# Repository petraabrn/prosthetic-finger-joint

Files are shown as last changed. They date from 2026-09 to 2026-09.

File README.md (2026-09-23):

# Cable-Driven Prosthetic Finger Joint & Testing Rig

> **A motorized, cable-actuated prosthetic finger prototype featuring tactile force feedback, rapid 3D prototyping, and Arduino control.**

This project is an experimental prototype of an articulated prosthetic finger that curls and extends using motorized pull strings (cables). Built as a low-cost mechatronics prototype, the setup combines mechanical 3D-printed parts, a motor drive system, and sensors to detect touch and adjust grip.

---

## 1. How the System Works

```text
               [ Arduino Controller (C++) ]
                            │
        ┌───────────────────┴───────────────────┐
        ▼                                       ▼
 [ Motor & Cable Rig ]                   [ Sensor Feedback ]
 • Servo / Stepper Motor                 • Pressure sensor (force-sensitive)
 • Motor Pulley                          • Ultrasonic distance sensor
 • Nylon tendon cable (pulls finger)     • Visual LED indicator
        │                                       │
        └───────────────────┬───────────────────┘
                            ▼
                [ 3D-Printed Finger ]
                • 3-joint trapezoidal segments
                • Paracord spine (keeps it aligned)
                • Bends from flat (0°) to full grip (90°)

```

## 2. Challenges & Iterations

* **Actuation & Torque:** The initial stepper motor repeatedly stalled under tendon load due to low torque and battery voltage drop. Upgraded to a dedicated servo motor and stabilized the power rail, eliminating stalls and achieving a smooth 0° to 90° flexion grasp in under 1 second.
* **Tactile Sensing Circuit:** The default 470Ω pull-down resistor left the force-sensitive sensor insensitive to touch. Bench-tested resistors up to 1.5MΩ to retune the voltage divider, drastically lowering the activation threshold so gentle contact triggers immediate LED feedback.
* **Firmware Timing:** The microcontroller missed real-time touch events because synchronous serial writes and motor sweeps blocked the main loop. Restructured the C++ execution logic to poll sensor pins continuously, cutting contact detection latency to immediate responsiveness.
* **Joint Kinematics:** The original single-piece 3D-printed flexure hinge bound up and risked fatigue snapping along layer lines. Redesigned the finger into segmented trapezoidal digits linked with a flexible paracord spine, delivering natural anatomical bending without pinching or lateral wobble.

---

## 3. Core Skills 

* **Embedded Microcontrollers:** Arduino programming (C++), motor control, reading analog sensor inputs
* **Electronics & Breadboarding:** Sensors, soldering
* **Mechanical CAD (SolidWorks):** Modeling parametric parts and testbed, 3D printing (FDM) in PLA & TPU.

---

## 4. Repository Structure

```
├── cad/
│   ├── assemblies/          # SolidWorks assembly files 
│   ├── parts/               # SolidWorks part files 
│   └── stl/                 # 3D print files 
├── electronics/             # Arduino sketches
└── docs/                    # Documentation and weekly logs

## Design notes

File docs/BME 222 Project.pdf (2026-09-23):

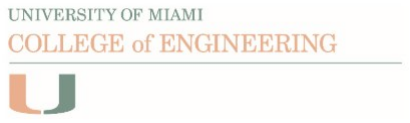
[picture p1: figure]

## Group 2G

Georgina Reyes
Guillermo Montenegro
Petra Kristian
Zoey White

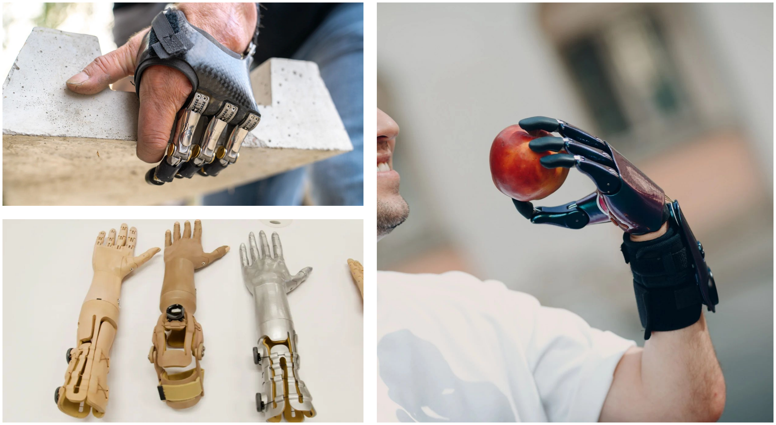
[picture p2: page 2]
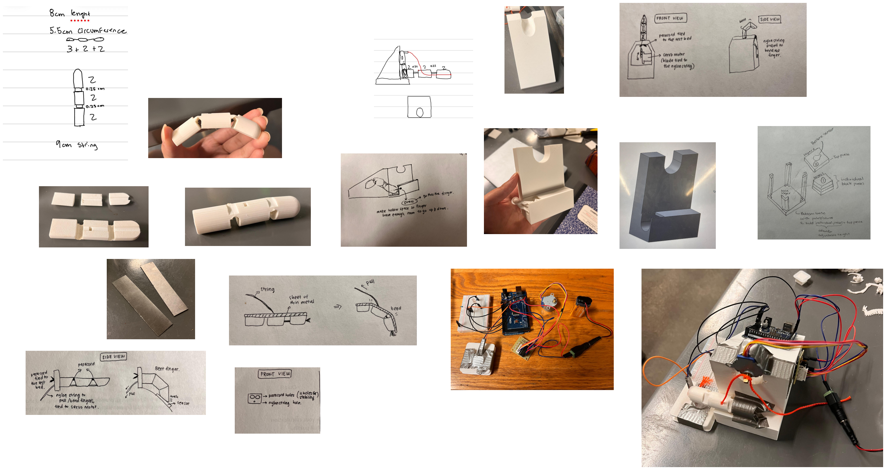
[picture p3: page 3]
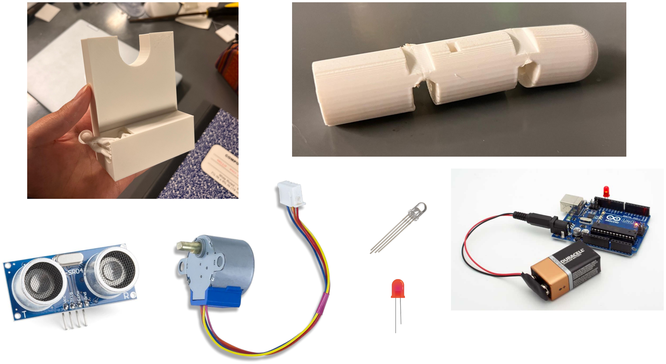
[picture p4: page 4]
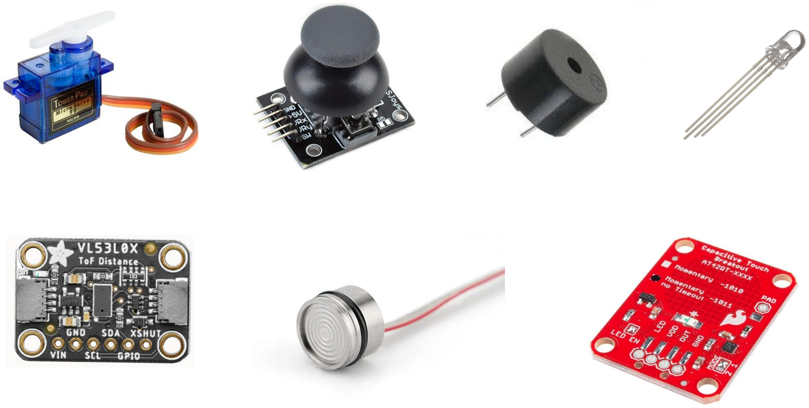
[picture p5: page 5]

## References

https://opcenters.com/a-simple-guide-to-getting-prosthetic-fingers/

https://primecareprosthetics.com/prosthetics/prosthetic-hand-partial-hand-fingers

https://thehill.com/changing-america/well-being/medical-advances/3510983-is-this-3d-printed-robotic-arm-the-future-of-prosthetics/ (https://thehill.com/changing-america/well-being/medical-advances/3510983-is-this-3d-printed-robotic-arm-the-future-of-prosthetics/)

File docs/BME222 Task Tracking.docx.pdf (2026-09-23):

BME221 DESIGN PROJECT WORK LOG – TEAM 2G

Finger prosthetic that is moved up & down with string(s) attached to a pulley (stepper motor). The finger will have a pressure sensor at the tip

Task Tracking Table (on going)

Task | Owner(s) | Date Assigned | Target Completion | Status | Notes / Dependencies
Revise and reprint finger & test bed | Guillermo Zoey | 03/02 | 03/20 | Done
Change stepper motor to servo, and/or change pressure sensor to distance sensor | Petra | 04/01 | 04/07 | Done
Final video and demo | All | 04/05 | 04/16 | In Progress
Rough design + measurements of finger and test bed on solidworks | Guillermo Zoey | 02/15 | 02/25 | Done | Thicker string used to keep finger straight, while the thinner string is looped around pulley to bend the finger
Get strings & pressure sensor | Georgina | 02/15 | 02/18 | Done | Need 2 types of strings: thin nylon string, and thicker one (any material)
Simulate rotation using motor with string attached | Petra | 02/15 | 03/04 | Done

Print finger and test bed | Georgina Petra | 02/18 | 03/04 | Done
Collect measurements of stepper motor, the 2 strings, etc | Georgina | 02/15 | 02/20 | Done | Measure using caliper; Measurements given to person in charge of finger and test bed design
Pressure sensor and LED code | Petra | 02/15 | 02/19 | Done
Sketch of solidworks design and start solidworks | Guillermo Zoey | 02/18 | 02/18 | Done | Sketch the exact parts that we want to design on solidworks
“Proof of Progress” video | Georgina | 02/28 | 03/06 | Done
Speed up motor rotation & fix wire connections | Petra | 03/16 | 03/16 | Done | Solder wires

## Project Snapshot (Week 12)

Week of: 12

Major Goal for This Week: change arduino components (stepper motor -> servo motor; pressure sensor -> distance sensor), assemble all parts, working on video and demo script and editing

Technical Progress Summary

Parts have been printed, some arduino components will be changed

Questions for Instructor / TA

Issues that need escalation

Team Process Check-In (Weekly)

- What Went Well This Week
- We were able to print the finger and test bed
- Challenges We Faced
- We are still trying to improve the finger design. Using just a paracord as the backbone on the finger wouldn’t be stable enough, so we might need to design a joint
- What We Will Change for Next Week
- We’ve been having problems with the pressure sensor not detecting any touch/pressure since it requires constant contact at a specific area. So we were thinking of changing the pressure sensor to an ultrasonic distance sensor. With the distance sensor, we can set the LED to gradually brighten as the finger moves closer to the distance sensor. This option might work better with a stepper motor. Another option is to set the LED to light up when the finger reached a certain distance threshold from the sensor, which might work better with a servo motor

Next Steps / Action Plan (Update this section during/after meeting)

- Key tasks for next week
- Responsible team members
- Required resources or instructor input
- Risks or uncertainties to monitor

## Project Snapshot (Week 11)

Week of: 11

Major Goal for This Week: Complete revision for finger and motor test bed designs and submit for printing. Prepare for demos (in two weeks).

Technical Progress Summary

Finger Prototype: Try redesigning the original prototype to include the metal plate. If not possible, a new design will be submitted (already completed, awaiting printing).

An updated mount was sent for printing.

Questions for Instructor / TA

Issues that need escalation

Team Process Check-In (Weekly)

- What Went Well This Week
- We were able to revise design for finger, test bed, and sensor
- Challenges We Faced
- Getting designs in on time to avoid long printing queues
- The stepper motor is still not strong enough to bend the fingers.
- What We Will Change for Next Week
- Get paracord
- Start recording demos
- We might need to switch to servo motor because the stepper motor we use is not fast/strong enough
- We might want to change the design of the finger by using a paracord instead of a thin plastic / metal. Or we can stick to using a thin plastic / metal plate, but still change the shape of each finger component to a trapezium

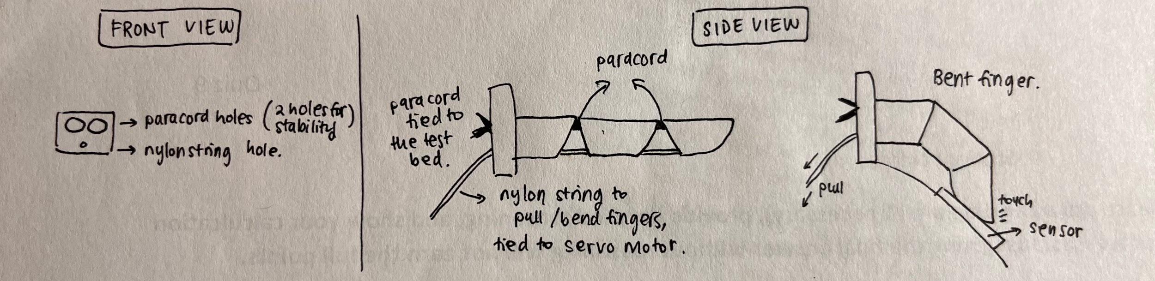
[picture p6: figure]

Note: Need to make joint to make sure each finger part won't slip or overlap each other.

Next Steps / Action Plan (Update this section during/after meeting)

- Key tasks for next week
- Responsible team members
- Required resources or instructor input
- Risks or uncertainties to monitor

## Project Snapshot (Week 10)

Week of: 10

Major Goal for This Week: Revise finger and motor test bed designs, design sensor test bed

Technical Progress Summary

Finger and motor test bed are in process of redesigning

Questions for Instructor / TA

Here’s a rough sketch of the sensor test bed. I wanted to get your opinion before moving forward.

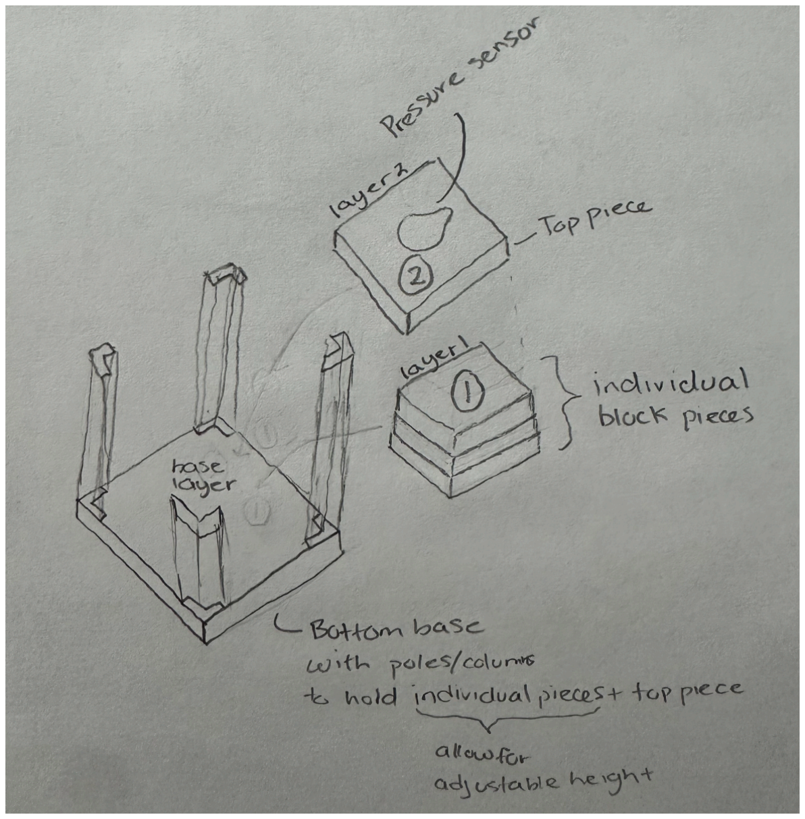
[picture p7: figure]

Issues that need escalation

Team Process Check-In (Weekly)

- What Went Well This Week
- Narrowing down design plans and streamlining our testing setup so we can evaluate the working parts all at once instead of reprinting separate parts
- Challenges We Faced:
- Coming up with motor test bed and finger designs improvements
- What We Will Change for Next Week
- Focusing on multipurpose model to streamline testing and reduce material waste

Next Steps / Action Plan (Update this section during/after meeting)

- Key tasks for next week

- Make motor piece insert a slot instead of trying to fit it perfectly into the testbed
- Using a drill press or wood screw to screw in motor piece
- Make locating dimples instead of actual holes in the design
- Redesign finger: make the first digit a square for more stability
- Simplify testbed design to be less wasteful with material
- Make sensor test bed as small as possible
- Use wedges to adjust the height
- Responsible team members
- Guillermo & Zoey: finger and testbed revision
- Georgina: pressure sensor testbed design
- Petra: motor mechanics
- Required resources or instructor input
- Drill press or wood screw
- Thinner string
- Risks or uncertainties to monitor
- Ensuring proper bending of the finger prototype with new design
- Simplifying sensor testbed, taking into account friction & resolution (if using wedges)

## Project Snapshot (Week 9)

Week of: 9

Major Goal for This Week: Fix test bed and finger design, make motor rotation faster, strengthen wire connections

Technical Progress Summary

We are revising our test bed & finger design and were able to fix the arduino components

Questions for Instructor / TA

Issues that need escalation

Team Process Check-In (Weekly)

- What Went Well This Week:

- The motor is now able to rotate faster
- We fixed the connections to the sensor by soldering the wires
- Challenges We Faced
- The wires were loosely connected to the sensor, so the readings were inconsistent. We had to rely on tape at first.
- The serial monitor will only print the readings of the sensor after the motor rotates clockwise and counterclockwise. However, we wanted it to print the recordings as soon as force was detected by the sensor. Applying Interrupt Service Routine (ISR) might work.
- The batteries died pretty quickly, so it was difficult to keep it running for long during trials. Besides that, the motor specifically needs 5V battery and we're currently using 9V. Not sure if this impacts the motor performance at all.
- The motor can now rotate faster, but it might still not be strong/fast enough to pull the fingers. We will be testing the new finger design using a sheet of metal to connect the finger parts, so hopefully it will be more elastic and easier to pull.
- What We Will Change for Next Week

Next Steps / Action Plan (Update this section during/after meeting)

- Key tasks for next week
- Responsible team members
- Required resources or instructor input
- Risks or uncertainties to monitor

## Project Snapshot (Week 8)

Week of: 8

Major Goal for This Week: Revise finger and test bed, complete “Proof of Progress” Video

Technical Progress Summary

Parts printed but needs revision

Questions for Instructor / TA

- Would TPU be a good alternative material to use to print the finger, or is it too flimsy?
- How would you recommend securing the moving finger on a static test bed? Or should we stick to our idea (in the “What We Will Change for Next Week” section)?

Issues that need escalation

Team Process Check-In (Weekly)

- What Went Well This Week
- Finalized the rough design on the finger and test bed to mount the motor
- Printed all parts (still needs further revision)
- Challenges We Faced
- Trying to figure out how to bend the flat part that connects the finger. We initially printed 2.5mm of that flat part and had to file the middle of it so it bends. We’re concerned that it will brake if it bends too much/too often, or the motor won't be strong enough to bend the finger
- The flat part is not long enough, so the finger can only bend partially

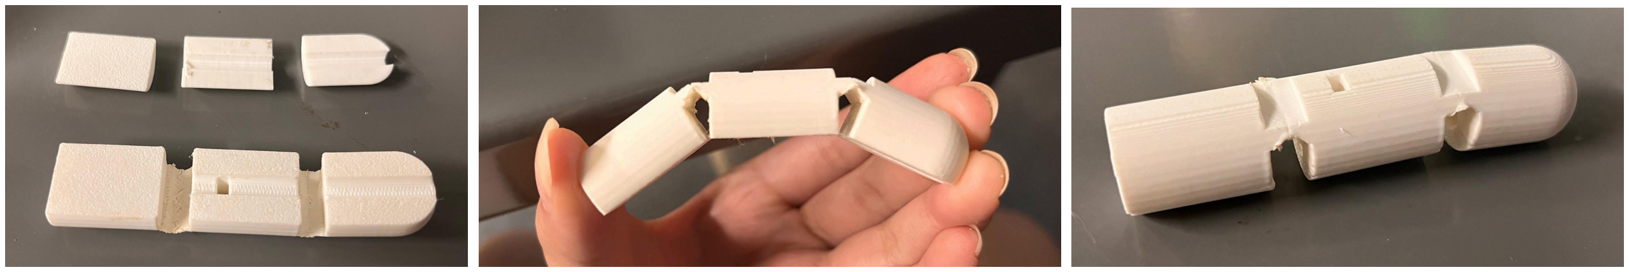
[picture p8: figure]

- With our current test bed design, the finger will be static. So we’re still trying to figure out the best way to stick it in the test bed while being able to bend up and down

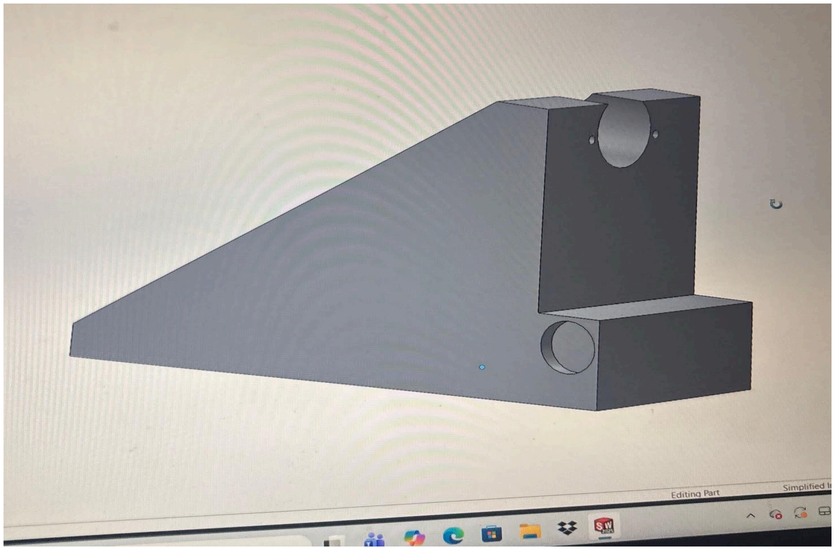
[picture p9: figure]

- What We Will Change for Next Week

- Revise design of finger: longer flat part with around 1.5–2mm thickness. Still need to file the middle so it can bend. Also make a small hole on the side to screw to the test bed
- Revise design for test bed to insert the finger: make a hole and insert a screw that goes through the finger (maybe. need suggestions)

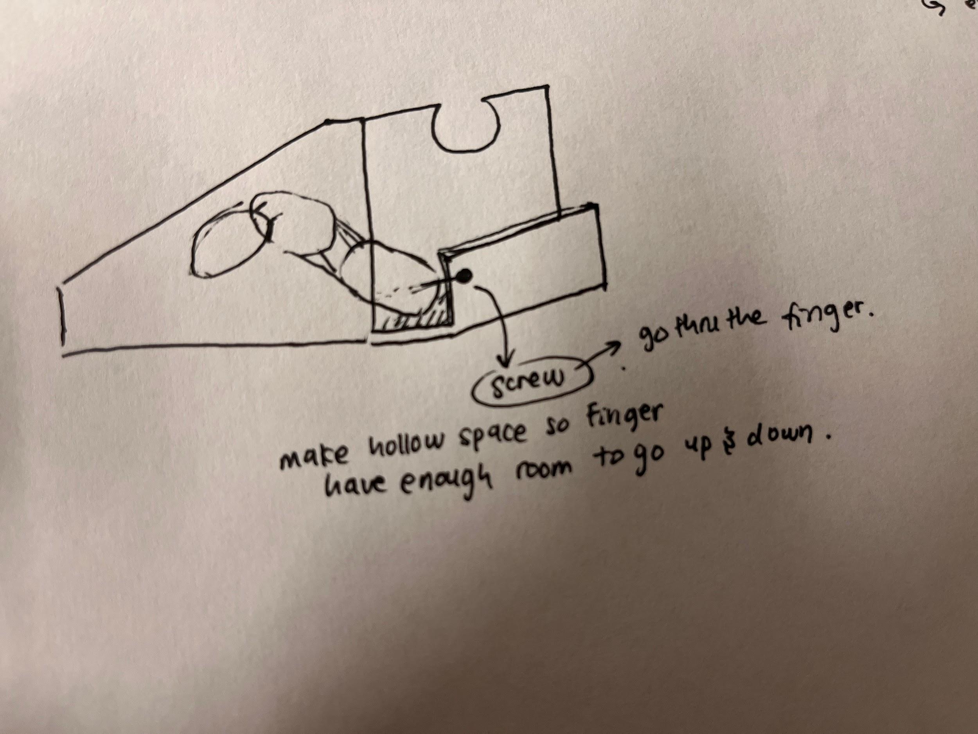
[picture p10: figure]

Next Steps / Action Plan (Update this section during/after meeting)

- Key tasks for next week
- Test motor capabilities to bend finger up and down
- Proof of concept video
- Responsible team members
- Required resources or instructor input
- Risks or uncertainties to monitor

Thin metal/stainless steel so more flexible to bend, find at machine shop

Redesign the finger to have a slot in the middle of the finger to slide the steel in. can also make the top flat, so we can screw the steel on top

## Project Snapshot (Week 7)

Week of: 7

Major Goal for This Week: Print parts, get arduino working

Technical Progress Summary

Code and arduino setup works well, will finalize parts design and get them printed

Questions for Instructor / TA

Issues that need escalation

Team Process Check-In (Weekly)

- What Went Well This Week:
- We were able to get the code running to activate LED, sensor, and motor
- Challenges We Faced:
- Finding the right resistor for the pressure sensor (we initially used 470R). The sensor needs to be pressed hard for it to detect force and light up the LED. Experimented using 100K, 330K, 680K, 910K, and 1.5M resistors. It was more sensitive to touch now that we used the 1.5M one. Most of the time, it still needs to be “activated” by pressing on the cable connections. The touch also must stay for approx 1-4 sec and use a slight force for it to be able to light up the LED
- Code will only print pressure/force level after printing ‘clockwise’ and ‘counter-clockwise’, even if the LED lights up when detecting force. So usually, it will print ‘force level = 0.00’ bcs it prints only after rotation, not every time it detects force. This doesn’t matter now, but might be important when we eventually test various forces.
- Difficulty designing the holes to connect finger
- What We Will Change for Next Week:
- Maybe make the sensor a little bit further up than the finger, so the rotation of the motor can “push” the finger to the sensor, rather than just touching it. Another option is to use weights/screws to make the finger tip heavier, adding force

Next Steps / Action Plan (Update this section during/after meeting)

- Key tasks for next week:
- Test the prototype
- Get the parts revised if needed
- Responsible team members
- Required resources or instructor input
- Risks or uncertainties to monitor

## Project Snapshot (Week 6)

Week of: 6

Major Goal for This Week: Get all materials, finalize code, design draft for finger and test bed

Technical Progress Summary

Prototypes built or tested, Data collected, Models or simulations run, Research completed. Make sure to include who contributed to the progress

Requirement | How to Measure | Status | Adjustment Plan (If failed)
Pressure sensor must detect a minimum force of ___ | Check if LED feedback is detected and serial monitor shows pressure change dg Check if the LED lights up when the finger puts pressure on the sensor. | | Adjust values
Finger must achieve a 90 degree bend when pulled and 0 when released | Use protractor to check contractions | | Increase motor pulley diameter

Questions for Instructor / TA

Would the motor be strong enough to pull the string and bend the finger, theoretically?

Would it be better to put the sensor on the tip of the finger or on the ground for the finger to touch?

Issues that need escalation

Meeting Notes

- Split design and make channel in the middle and glue back together
- Avoids overhang
- Make test bed to see how thick it has to be → test flexibility
- Alignment pins and/or glue
- Two pressure sensors: 1 on finger + 1 on ground
- Have them touch each other

- Minimize bending by making hole where plastic part is shorter

Team Process Check-In (Weekly)

- What Went Well This Week: We finalized the prototype sketches and collected all measurements to start working on solidworks.
- Challenges We Faced: Figuring out the most effective mechanical placement for the pulley/string system for proper finger flexion.
- What We Will Change for Next Week: Transition to solidworks modeling

Next Steps / Action Plan (Update this section during/after meeting)

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

## Project Snapshot (Week 5)

Week of: 5

Major Goal for This Week: Finalize draft presentation & group

Technical Progress Summary

Prototypes built or tested, Data collected, Models or simulations run, Research completed. Make sure to include who contributed to the progress

Questions for Instructor / TA

Issues that need escalation

Team Process Check-In (Weekly)

- What Went Well This Week
- Challenges We Faced
- What We Will Change for Next Week

Next Steps / Action Plan (Update this section during/after meeting)

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

Goals for video assignment:

Testbed

- file/cut down motor insert section
- Mount screw/tape motor system onto testbed

Finger Piece

- Hold down or tape finger in place

Video

- Take video of all working parts
- Create transcript
- Put video clips together

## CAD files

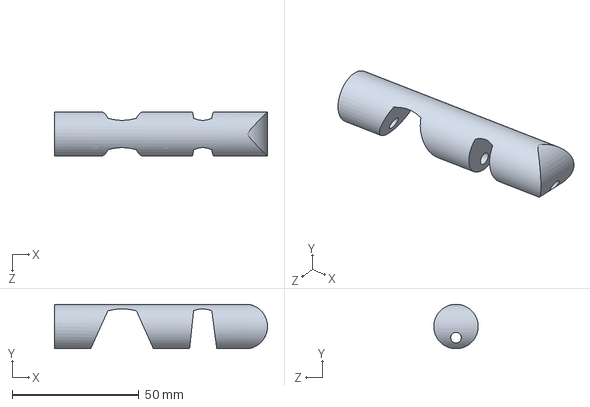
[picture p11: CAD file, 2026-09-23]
cad/parts/Finger Proto.SLDPRT
83.9 x 17.5 x 17.5 mm

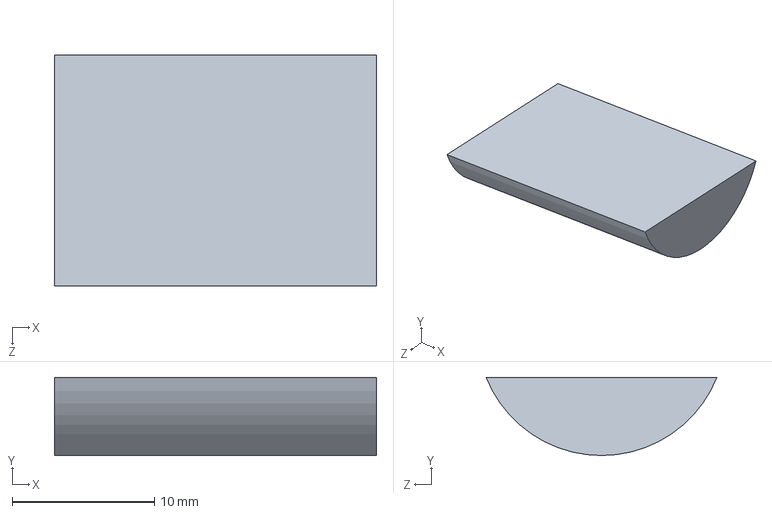
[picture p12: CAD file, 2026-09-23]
cad/parts/Bottom B1.SLDPRT
22.7 x 5.49 x 16.3 mm

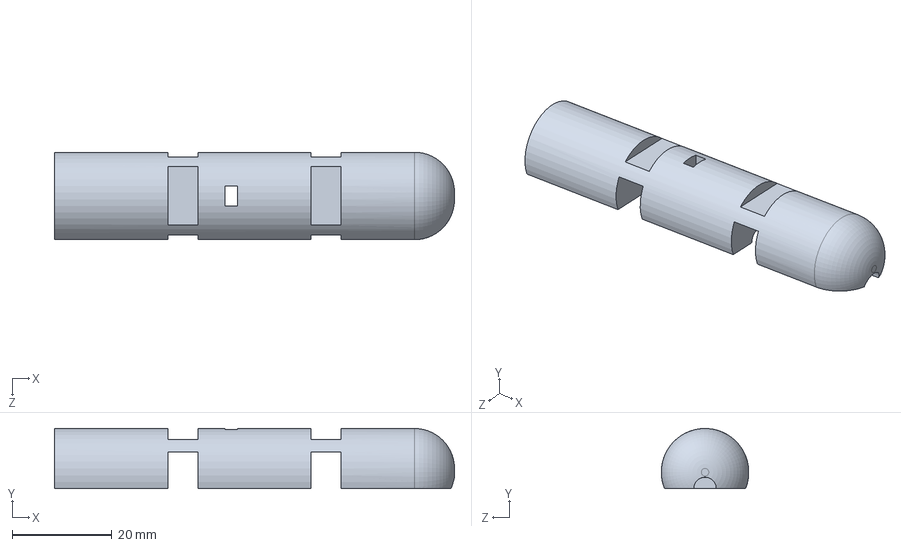
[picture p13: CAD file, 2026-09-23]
cad/parts/Top Cross.SLDPRT
80.0 x 12.0 x 17.5 mm

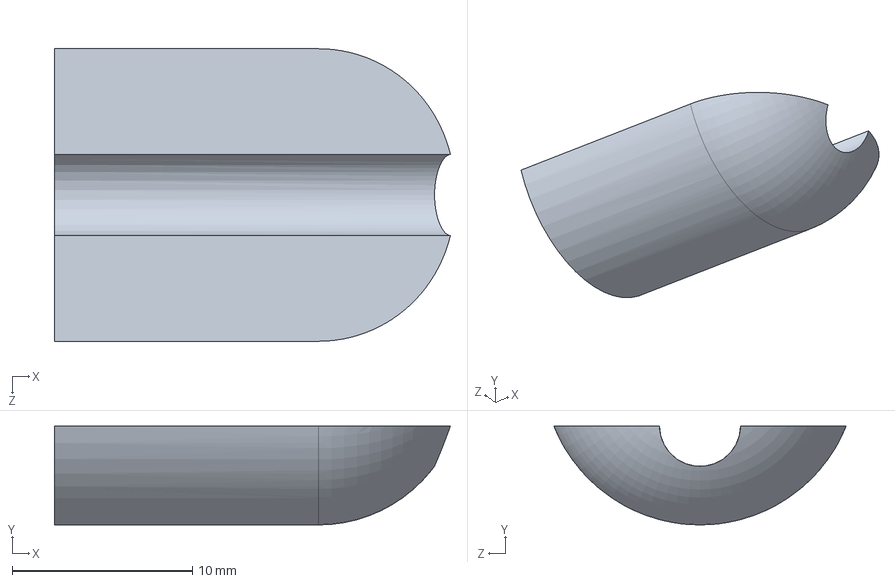
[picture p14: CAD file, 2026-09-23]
cad/parts/Bottom B3.SLDPRT
22.0 x 5.49 x 16.3 mm

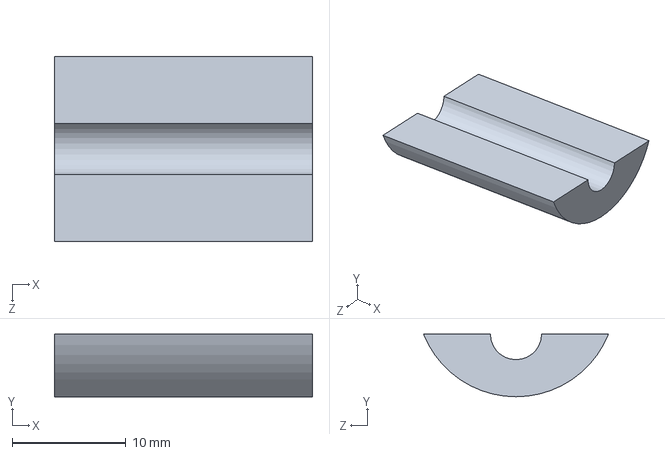
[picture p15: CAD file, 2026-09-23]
cad/parts/Bottom B2.SLDPRT
22.7 x 5.49 x 16.3 mm

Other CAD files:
cad/stl/Bottom B1.STL
cad/stl/Bottom B2.STL
cad/stl/Bottom B3.STL
cad/stl/Top Cross.STL

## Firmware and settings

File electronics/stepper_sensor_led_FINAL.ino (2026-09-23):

#include <Stepper.h>

const int stepsPerRevolution = 2048;  // Number of steps for a full 360-degree rotation 
const int ledPin = 5;                // Digital pin connected to the LED
const int trigPin = 6;             // Trig pin connected to the distance sensor
const int echoPin = 7;             // Trig pin connected to the distance sensor

Stepper myStepper(stepsPerRevolution, 8, 10, 9, 11);  // Initialize the stepper library for pins 8 through 11

void setup() {
  
  myStepper.setSpeed(10);   // Rotation speed of 100 rpm
  pinMode(ledPin, OUTPUT);  // LED is an output
  pinMode(trigPin, OUTPUT);  // Distance sensor is an output
  pinMode(echoPin, INPUT);  // Distance sensor is an input
  Serial.begin(115200);     // Initialize the serial port to see values on screen
  Serial.println("Starting");

}

void loop() {
  long duration;
  float cm;

  // Sense and fade
  digitalWrite(trigPin, LOW);
  delayMicroseconds(2);
  digitalWrite(trigPin, HIGH);
  delayMicroseconds(10);
  digitalWrite(trigPin, LOW);

  duration = pulseIn(echoPin, HIGH);
  cm = (duration * 0.034) / 2; 

  // LED brightness control
  int brightness = map(cm, 2, 20, 255, 0); 
  brightness = constrain(brightness, 0, 255); 
  analogWrite(ledPin, brightness); 

  // If your finger is close, move the motor just a tiny bit
  if (cm <= 10 && cm > 2) {
    myStepper.step(10); 
    Serial.print("Distance: "); Serial.println(cm);
    Serial.print("Brightness: "); 
  } 
  else if (cm > 25) {
    // If nothing is there, slowly move back to open
    myStepper.step(-10);
  }

  // Small delay so the sensor stays responsive
  delay(10); 
}

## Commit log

2026-09-23 CAD Assembly Files
2026-09-23 Assembly files
2026-09-23 3D print files
2026-09-23 Arduino sketch
